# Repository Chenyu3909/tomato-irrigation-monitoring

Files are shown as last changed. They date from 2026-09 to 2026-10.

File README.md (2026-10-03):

# Raspberry Pi Environmental Monitoring System

I built this Raspberry Pi monitoring system for a tomato irrigation experiment at the **Boyce Thompson Institute (BTI)** under the mentorship of **Yao Chen, Translational Scientist at BTI/Cornell**. The goal was to collect soil moisture, temperature, and humidity continuously in the field without relying on manual measurements.

I designed the hardware setup, integrated four analog soil-moisture sensors through an ADS1115 ADC, wrote the Python data logger, configured it to run automatically with `systemd`, and deployed the completed system outdoors. It logged measurements every **15 minutes for 37 days**, producing more than **34,000 individual sensor measurements**.

## Engineering Objective

I needed the system to:

- Read four analog soil-moisture sensors from a Raspberry Pi
- Measure ambient temperature and humidity
- Timestamp and save every reading
- Run without a laptop connected
- Recover from temporary DHT22 read errors instead of stopping
- Operate outdoors for several weeks
- Store the data for later analysis

## System Architecture

```text
                         ┌── DHT22
                         │   Temperature
                         │   Humidity
Raspberry Pi 4 ──────────┤
                         │
                         └── ADS1115 ADC
                                │
                                ├── Soil Sensor 1
                                ├── Soil Sensor 2
                                ├── Soil Sensor 3
                                └── Soil Sensor 4
```

The DHT22 connects directly to the Raspberry Pi. Because the Pi has no built-in analog inputs, I used an **ADS1115 16-bit ADC** to read the four capacitive soil-moisture sensors, one on each analog channel.

## Hardware Development

I built the system in stages rather than wiring everything at once. I started with the DHT22, then added the ADS1115 and tested the soil sensors before combining all four into the final setup.

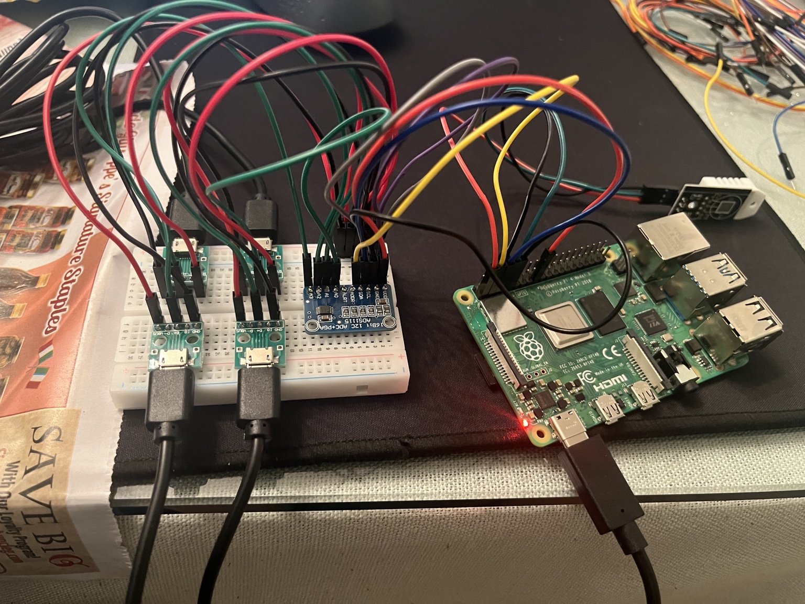
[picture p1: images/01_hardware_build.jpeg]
Raspberry Pi hardware build


*Raspberry Pi, breadboard, ADS1115, and sensor wiring during development.*

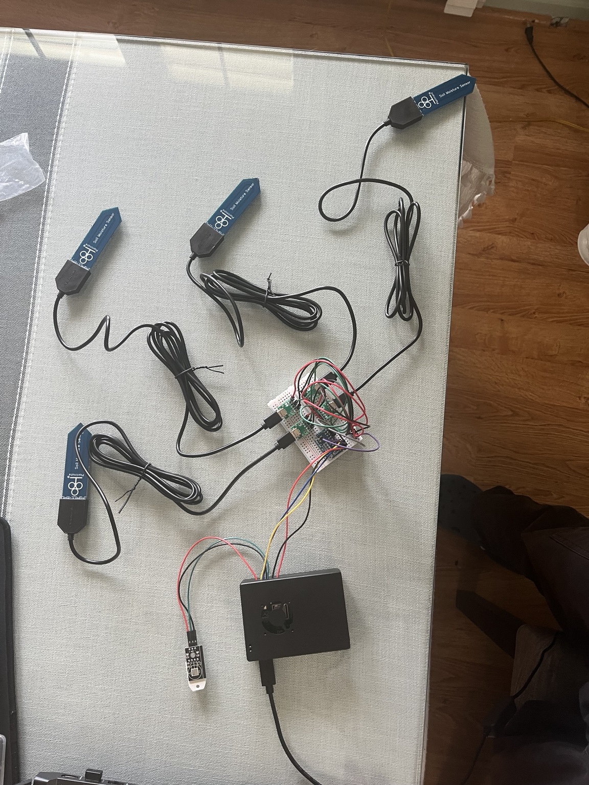
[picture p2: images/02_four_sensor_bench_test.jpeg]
Four-sensor bench test


*Bench testing the complete four-sensor setup before field deployment.*

The outdoor enclosure is documented by the exported STL files [`cad/enclosure.stl`](cad/enclosure.stl) and [`cad/enclosure-lid.stl`](cad/enclosure-lid.stl).

## Software and Data Logging

The monitoring software is written in **Python** and is available here:

**[View the full sensor logger →](src/sensor_logger.py)**

The logger initializes the DHT22 and ADS1115, reads temperature, humidity, and all four soil-moisture sensors, timestamps each sampling cycle, and appends the readings to a CSV file. Each soil sensor is recorded as both a raw ADC value and voltage.

The sampling interval is set to 900 seconds (15 minutes):

```python
SAMPLE_INTERVAL_SECONDS = 900
```

I added error handling for temporary DHT22 read failures so a bad reading would not stop a long-term logging session. The required Python packages are listed in [`requirements.txt`](requirements.txt).

## Automated Operation

I configured the logger as a Linux `systemd` service, included at [`systemd/sensor_logger.service`](systemd/sensor_logger.service).

The included service file reflects the original field deployment, where the logger was stored as `/home/chenyuyang/sensor.py`. The same logger is organized in this repository as [`src/sensor_logger.py`](src/sensor_logger.py).

This let the Raspberry Pi run the monitoring program automatically instead of requiring me to manually start the script. During the original deployment, the service used `/home/chenyuyang` as its working directory and wrote readings to `environment_log.csv`.

## Field Deployment

After indoor testing, I installed the electronics in an enclosure and deployed the system with the tomato plants.

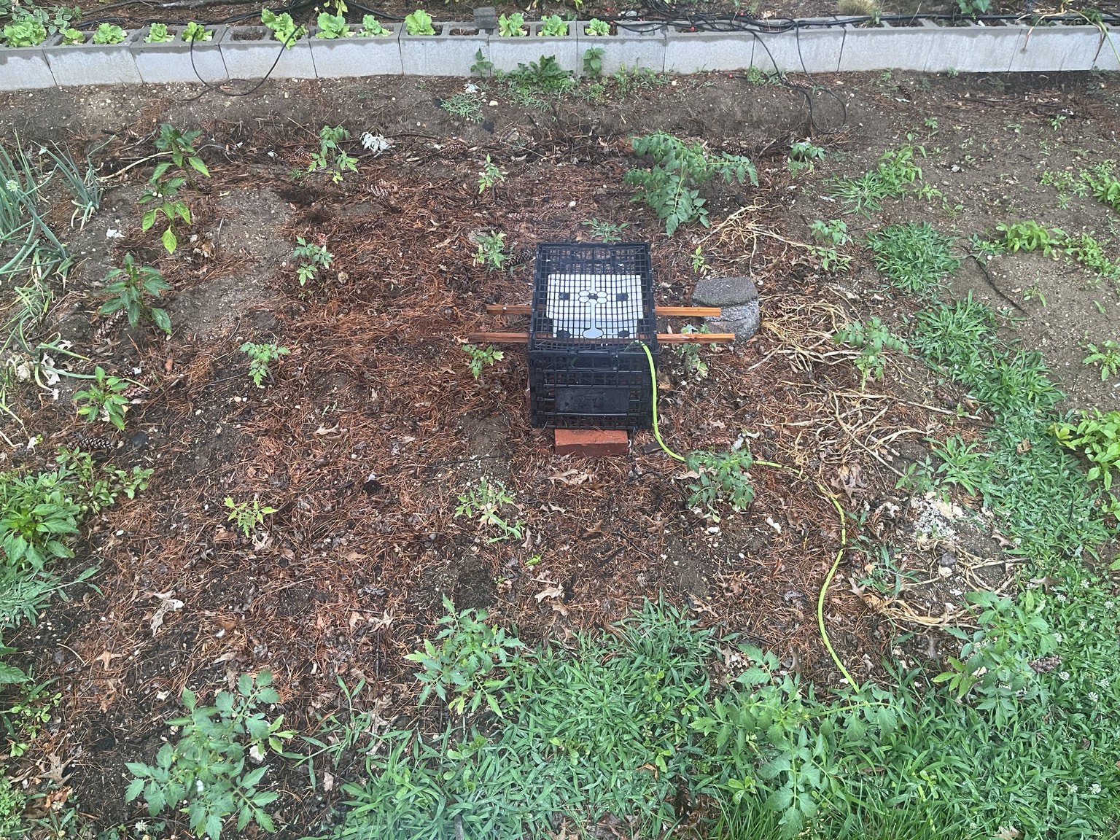
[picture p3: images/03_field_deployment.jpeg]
Field deployment


*Monitoring system deployed in the planting area.*

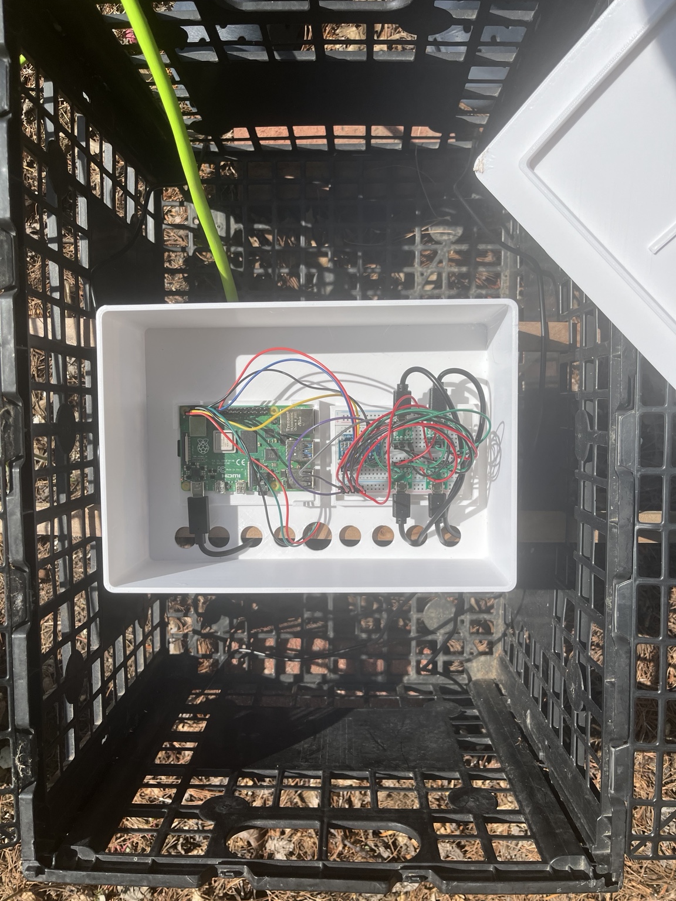
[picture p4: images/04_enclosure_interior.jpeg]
Enclosure interior


*Raspberry Pi and sensor electronics inside the outdoor enclosure.*

The system remained in the field for **37 days** while recording measurements every 15 minutes.

## Development Process

The main stages were:

1. Test temperature and humidity logging with the DHT22
2. Connect and configure the ADS1115 over I2C
3. Test individual capacitive soil-moisture sensors
4. Connect four sensors to separate ADC channels
5. Combine all sensor readings into one Python logger
6. Write timestamped readings to CSV
7. Set the logger to a 15-minute sampling interval
8. Configure automatic operation with `systemd`
9. Package the electronics for outdoor use
10. Deploy the completed system in the field

The earlier CSV files in `data/` preserve some of these development stages.

## Field Performance

The final logger produced [`data/environment_log.csv`](data/environment_log.csv). I also kept the earlier DHT-only and pre-deployment logs rather than deleting them.

### Temperature and Humidity

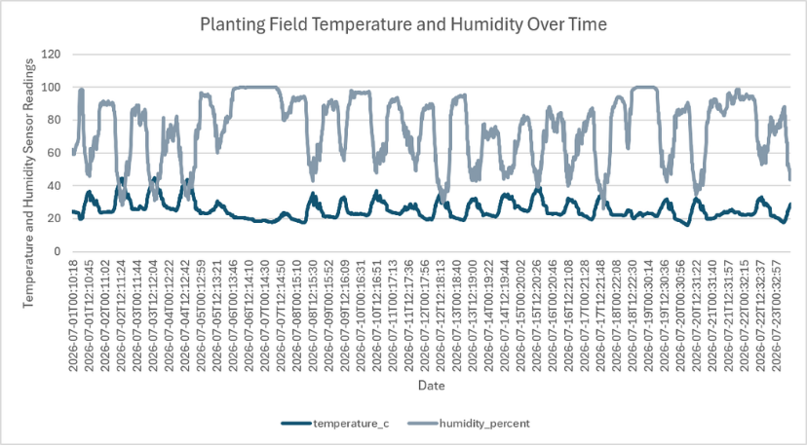
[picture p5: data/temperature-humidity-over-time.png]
Temperature and humidity over time


### Soil Moisture

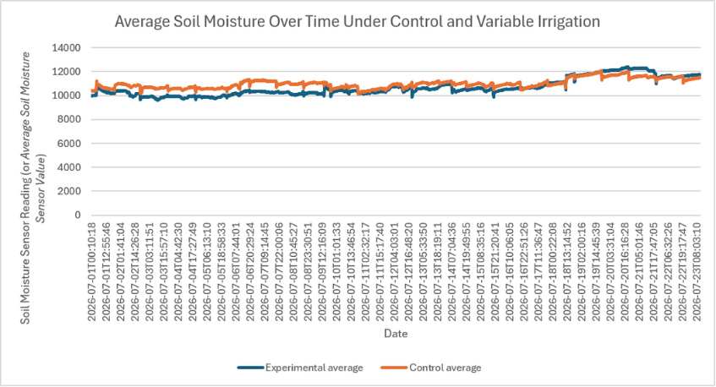
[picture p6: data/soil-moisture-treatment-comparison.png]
Average soil moisture by irrigation treatment


The graphs are included here mainly to show the output of the monitoring system. The soil sensors report raw ADC readings rather than calibrated volumetric water content, so I kept the interpretation descriptive.

## Research Application

The engineering system supported a larger experiment asking:

> **How does soil moisture variability affect tomato fruit quality and blossom-end rot (BER)?**

The experiment included **20 tomato plants**, **5 cultivars**, and two irrigation treatments beginning July 3, 2026.

| Treatment | Irrigation schedule | Sensors |
| --- | --- | --- |
| Control | 10 minutes every day | Soil 3 & 4 |
| Experimental | 30 minutes every 3 days | Soil 1 & 2 |

The irrigation schedules were controlled separately from the Raspberry Pi. The system documented in this repository was used for **monitoring and data logging**, not irrigation control.

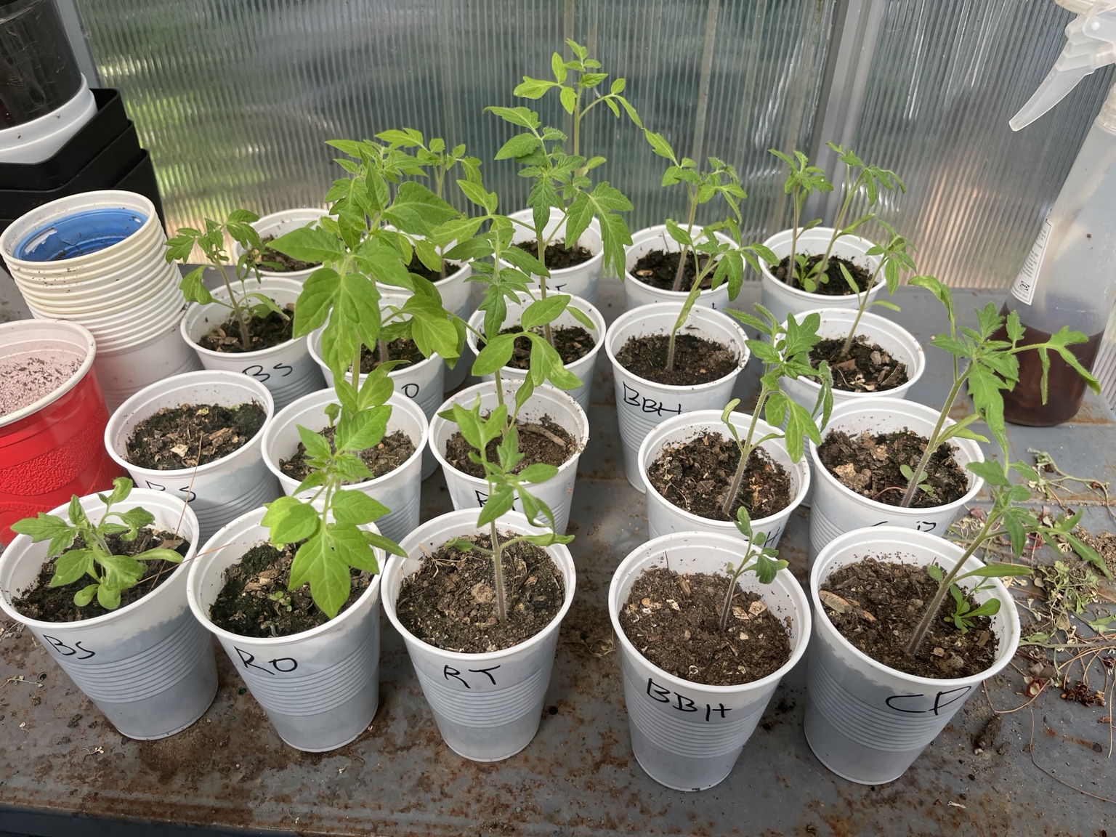
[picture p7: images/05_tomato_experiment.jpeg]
Tomato experiment


*Monitoring system positioned in the experimental growing area.*

### BER Observation

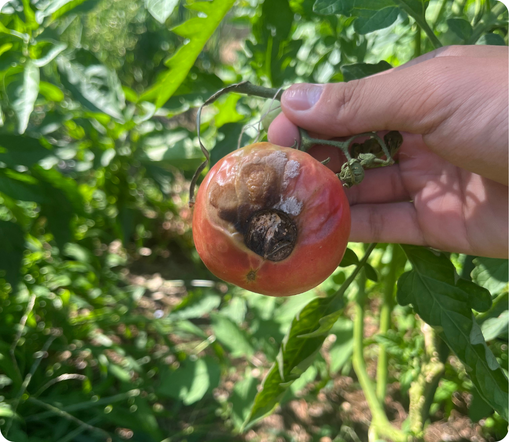
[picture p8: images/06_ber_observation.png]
Tomato showing blossom-end rot


*A fruit with visible blossom-end rot symptoms observed during the study.*

Fruit development was still ongoing during the documented study period, and BER observations were limited. I therefore did not use this observation to claim that either irrigation treatment caused or prevented BER.

The larger research project is summarized in the [**research poster (PDF)**](assets/poster/research-poster.pdf).

## Bill of Materials

Hardware and irrigation materials purchased for the project totaled **$280.77**. Project costs were funded by the **Boyce Thompson Institute (BTI)**.

| Component | Cost | Role |
| --- | ---: | --- |
| Raspberry Pi 4 | $134.99 | Data logging and storage |
| DHT22 | $13.99 | Temperature and humidity |
| ADS1115 | $7.99 | Analog-to-digital conversion |
| Soil Sensors #1 & #2 | $22.99 | Soil-moisture sensing |
| Soil Sensors #3 & #4 | $22.99 | Soil-moisture sensing |
| Breadboard and wires | $9.99 | Prototyping and wiring |
| Drip irrigation system | $26.99 | Experimental irrigation |
| Water timer | $40.84 | Irrigation timing |
| **Total** | **$280.77** | |

## Repository Structure

```text
tomato-irrigation-monitoring/
├── assets/poster/       # research poster
├── cad/                 # enclosure STL exports
├── data/                # field data, test data, and plots
├── images/              # build and deployment photos
├── src/                 # Python logger
├── systemd/             # automatic logger service
├── requirements.txt
└── README.md
```

## Running the Logger

Install the required libraries:

```bash
pip install -r requirements.txt
```

Run the logger:

```bash
python3 src/sensor_logger.py
```

The program creates or appends to `environment_log.csv` in its working directory. Hardware connections must match the GPIO and ADS1115 channel assignments in `sensor_logger.py`.

## Future Improvements

If I rebuilt the system, I would:

- Calibrate the soil sensors to estimate volumetric water content
- Improve weather protection for the electronics
- Add remote monitoring so I could check incoming data without physically accessing the Pi
- Add more sensors for greater spatial replication
- Integrate irrigation control with the Raspberry Pi

## Technologies

`Python` · `Raspberry Pi` · `Linux` · `systemd` · `I2C` · `ADS1115` · `DHT22` · `Analog Sensors` · `Data Logging`

## Acknowledgments

This system was developed for a tomato irrigation research project at the **Boyce Thompson Institute (BTI)** under the mentorship of **Yao Chen, Translational Scientist at BTI/Cornell**. Project hardware and materials were funded by BTI.

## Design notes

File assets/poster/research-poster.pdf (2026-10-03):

Metric | Current Status
Monitoring Duration | 37 Days
Sample Interval | 15 Minutes
Total Measurements | 34610
Irrigation Treatments | Began July 3

## 5.3 Monitoring Metrics

# SUMMER 2026

# BER - BLOSSOM END ROTTING

# RELATION TO SOIL MOISTURE

## Investigating the Effects of Soil Moisture Variability on Tomato Fruit Quality and Blossom-End Rot Using an Automated Monitoring and Irrigation System

Blossom-end rot (BER) is a common physiological disorder in tomatoes that significantly reduces fruit quality and marketability (Topcu et al., 2022). While BER is often associated with calcium deficiency, research suggests that fluctuations in soil moisture can interfere with calcium transport within the plant (Nicolas et al., 2023). Understanding how soil moisture variability affects BER and overall fruit quality may help improve irrigation practices and crop productivity.

# STUDENT:

## Chenyu Yang East Meadow High School

1. INTRODUCTION | 4. ENGINEERING SYSTEM

# 3. METHODOLOGY

# 2. QUESTION/HYPOTHESIS

REFEFENCES | ACKNOWLEDGEMENT

# 5. PRELIMINARY RESULTS

6. FUTURE WORK | 7. CONCLUSION

How does soil moisture variability affect tomato fruit quality and blossom-end rot incidence?

Tomato plants exposed to inconsistent soil moisture will exhibit reduced fruit quality and increased blossom-end rot incidence compared to plants receiving consistent irrigation.

## Continue Monitoring

## Optimize Irrigation

## Expand Data Analysis

Twenty tomato plants were divided into two treatment groups:
Control Group: Consistent watering schedule (10min every day at 8:00 p.m.) Experimental Group: Variable watering schedule (30min every 3 days at 8:00 p.m.)
Tomato Varieties: Cherokee Purple, Better Boy, Beefsteak, Roma, Rutgers. Tomatoes are planted in a 5x4 pattern. Each column contains all five varieties to reduce the effect of variety as a confounding variable.

### Environmental Sensors

### Data Acquisition

### Embedded Computing Software

### Research Output

### 4 Moisture Sensors DHT22 Temperature / Humidity Sensor

### ADS1115 converts analog data into digital values

Raspberry Pi Automated continuous sampling | CSV Data
| Storage
| Timestamped
| Measurements

### Soil Moisture Trends Temperature / Humidity Analysis

I would like to thank my mentor, Researcher Yao Chen at Boyce Thompson Institute for direction, guidance, and support throughout the development of this project. I would also like to thank Cornell and BTI for this opportunity.

Thank you for your time and feedback.

5.1 Environmental Data - Temp/Humidity | 5.2 Environmental Data - Soil Moisture
5.4 Observations | 5.5 Key Findings One blossom-end rot (BER) case was observed in the control treatment; no BER symptoms have been observed in the experimental treatment to date. Because most fruit are still developing, additional monitoring is needed before treatment effects on BER incidence can be evaluated. The only ripe fruit is the one that shows symptoms consistent with BER.

Successfully developed an automated Raspberry Pi– based environmental monitoring system. Collected over 34,000 environmental and soil moisture measurements during a 37-day monitoring period.
Fruit development is ongoing; one BER case has been observed in the control treatment.
Continued monitoring will determine whether irrigation-induced soil moisture variability influences blossom-end rot incidence.

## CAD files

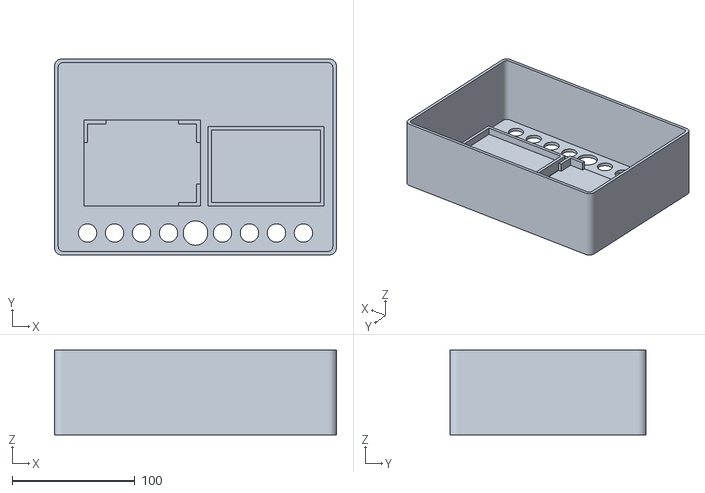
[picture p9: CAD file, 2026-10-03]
cad/enclosure.stl
230.0 x 160.0 x 69.0

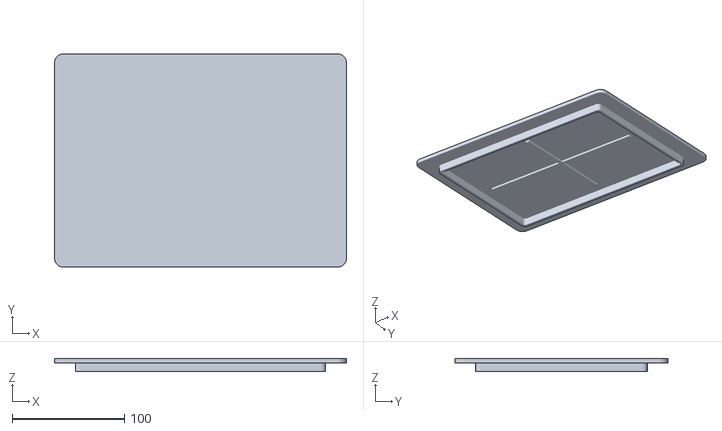
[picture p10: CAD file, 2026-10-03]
cad/enclosure-lid.stl
260.0 x 190.0 x 12.0

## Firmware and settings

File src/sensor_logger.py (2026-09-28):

import csv
import os
import time
from datetime import datetime

import adafruit_dht
import board
import busio
import adafruit_ads1x15.ads1115 as ADS
from adafruit_ads1x15.analog_in import AnalogIn

LOG_FILE = "environment_log.csv"
SAMPLE_INTERVAL_SECONDS = 900

dht_device = adafruit_dht.DHT22(board.D4)

i2c = busio.I2C(board.SCL, board.SDA)
ads = ADS.ADS1115(i2c)

soil1 = AnalogIn(ads, 0)
soil2 = AnalogIn(ads, 1)
soil3 = AnalogIn(ads, 2)
soil4 = AnalogIn(ads, 3)


def ensure_csv_header():
    if not os.path.exists(LOG_FILE):
        with open(LOG_FILE, "w", newline="") as file:
            writer = csv.writer(file)
            writer.writerow([
                "timestamp",
                "temperature_c",
                "humidity_percent",
                "soil1_value",
                "soil1_voltage",
                "soil2_value",
                "soil2_voltage",
                "soil3_value",
                "soil3_voltage",
                "soil4_value",
                "soil4_voltage"
            ])


def log_reading(row):
    with open(LOG_FILE, "a", newline="") as file:
        writer = csv.writer(file)
        writer.writerow(row)
        file.flush()


ensure_csv_header()

while True:
    try:
        timestamp = datetime.now().isoformat(timespec="seconds")

        temperature = dht_device.temperature
        humidity = dht_device.humidity

        row = [
            timestamp,
            temperature,
            humidity,
            soil1.value,
            round(soil1.voltage, 3),
            soil2.value,
            round(soil2.voltage, 3),
            soil3.value,
            round(soil3.voltage, 3),
            soil4.value,
            round(soil4.voltage, 3),
        ]

        log_reading(row)

        print(
            f"{timestamp} | Temp: {temperature} C | Humidity: {humidity}% | "
            f"Soil1: {soil1.value} | Soil2: {soil2.value} | "
            f"Soil3: {soil3.value} | Soil4: {soil4.value}"
        )

    except RuntimeError as error:
        print("Sensor read error:", error)
        time.sleep(2)
        continue

    except Exception as error:
        dht_device.exit()
        raise error

    time.sleep(SAMPLE_INTERVAL_SECONDS)

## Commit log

2026-09-28 Initial commit: Raspberry Pi environmental monitoring system
    [environment_log.csv, environment_log_old_dht_only.csv, environment_log_predeployment.csv]
2026-10-03 Add CAD directory
2026-10-03 Rename CAD files and research poster
    [enclosure-lid.stl, enclosure.stl]
2026-10-03 Polish README with project photos, BOM, CAD, and poster
2026-10-03 Add software section and link sensor logger
2026-10-03 Remove temporary CAD placeholder
